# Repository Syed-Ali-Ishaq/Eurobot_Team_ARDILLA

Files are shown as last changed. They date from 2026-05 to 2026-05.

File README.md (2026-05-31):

<p float="left" style="display:flex;justify-content:space-between;padding:0 5em 0 5em">
    
    
</p>
</br>

# Eurobot 2026 - Master Advanced Mechatronics

This is the official baseline repository for the International Challenge of the Master Advanced Mechatronics at Polytech Annecy-Chambéry.

<p style="text-align:center"> &#9888; This project must be run as a Dev Container &#9888; </p>

This year, PROJ703 and PROJ903 have the goal of tackling the challenge set for the Eurobot Contest 2026 (see the [Official Website](https://www.eurobot.org/eurobot-contest/eurobot-2026/)).

> *Winter is coming, and it’s time for the squirrels to stock up on hazelnuts so they can spend the whole winter in their soft, warm nests.</br> 
> But evil humans already took them all, put them in crates and are about to leave with them, and it will let squirrels starving for the next months!</br>
> Luckily it’s coffee time for the humans, and the squirrels have only few seconds to grab the hazelnut crates and hide it from the evil humans.</br>
> But will they have enough to pass the winter?*
>
> *Your strategies will be:*
> - *Let’s keep the hazelnuts warm.*
> - *To find is to keep!*
> - *Not too warm, not too cold.*
> - *Nest, sweet nest.*
> - *Lunch time!*

## Content
- [x] VSCode Dev Container Template (see [Development Container](https://containers.dev/) and [Setup ROS 2 with VSCode and Docker](https://docs.ros.org/en/kilted/How-To-Guides/Setup-ROS-2-with-VSCode-and-Docker-Container.html) for more info) </p>
To be run using one of the available tools (see [Supporting tools and services](https://containers.dev/supporting)) </p>
We suggest running this project on VSCode using the [Dev Containers extension](https://marketplace.visualstudio.com/items?itemName=ms-vscode-remote.remote-containers) (see [Developing inside a Container](https://code.visualstudio.com/docs/devcontainers/containers)) </p>
  - [x] devcontainer.json + Dockerfile based on [ROS 2 Workspace by Bruno-Pier Busque](https://github.com/BrunoB81HK/ros2-workspace-devcontainer-template/tree/main/src/ros2-workspace) (ROS 2 Humble and Ignition Gazebo Fortress on Ubuntu Jammy)
  - [X] ROS 2/Gazebo project template
    - [X] Simple Gazebo world with game mat based on the official Beta mat
    - [X] Simple robot for reference
- [ ] Reference documents

## Guidelines
- [ ] Every team must fork this repository.
- [ ] All team members must be listed as contributors to the corresponding fork.
- [ ] All team members must contribute to the corresponding fork.

</br>

---

<h1 style="text-align:center">
&#128063; Let's code/design/build some squirrels! &#128063;
<h1>

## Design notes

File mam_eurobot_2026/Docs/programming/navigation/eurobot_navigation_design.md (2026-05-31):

# Eurobot Navigation Package — Design Documentation

**Package:** `eurobot_navigation`  
**Team:** Team Yellow (ARDILLA) — Eurobot 2026  
**Files covered:** `MissionController.py`, `scan_frame_fixer.py`, `mapper_params_online_async.yaml`

---

## 1. Package Overview

The navigation package contains three components that work together to give the robot autonomous mobility and mission execution:

| Component | Role |
|---|---|
| `SimpleMissionController` | Top-level FSM — decides what the robot does and when |
| `ScanFrameFixer` | Thin adapter that corrects the LiDAR frame ID for SLAM Toolbox |
| `mapper_params_online_async.yaml` | SLAM Toolbox configuration for online async mapping |

---

## 2. System Architecture

```
[LiDAR driver]
    │  /scan  (wrong frame_id)
    ▼
[ScanFrameFixer]
    │  /scan_fixed  (frame_id = 'lidar_link')
    ▼
[SLAM Toolbox]  ←── mapper_params_online_async.yaml
    │  /map  +  TF: map → odom → base_link
    ▼
[Nav2 stack]  ←── NavigateToPose action server
    ▲
    │  navigate_to_pose action
    │
[SimpleMissionController]
    ├── /cmd_vel  ──────────────────► [robot base]
    ├── /gripper_controller/commands ► [gripper]
    └── /crate/detections ◄─────────── [ArucoCratePerception]
```

---

## 3. `ScanFrameFixer` Node

### Purpose

Some LiDAR drivers publish `/scan` with a generic or incorrect `frame_id` (e.g. `laser` or empty). SLAM Toolbox requires the scan's `frame_id` to match a known TF frame. This node is a **minimal relay** that rewrites the header and republishes.

### How it works

```
/scan  ──► [overwrite header.frame_id = 'lidar_link'] ──► /scan_fixed
```

Every incoming `LaserScan` message is mutated in place — only `header.frame_id` changes, all scan data passes through unchanged.

### Design rationale

Rather than patching the driver or adding a URDF static transform with the wrong name, this tiny node decouples the driver's output format from the SLAM Toolbox's expectation. It costs essentially zero CPU and can be removed once the driver is fixed upstream.

### ROS Interfaces

| Direction | Topic | Type |
|---|---|---|
| Subscribes | `/scan` | `sensor_msgs/LaserScan` |
| Publishes | `/scan_fixed` | `sensor_msgs/LaserScan` |

---

## 4. SLAM Toolbox Configuration (`mapper_params_online_async.yaml`)

SLAM Toolbox runs in **online asynchronous mapping** mode, building a live occupancy grid from LiDAR scans while the robot moves.

### Frame setup

| Parameter | Value | Meaning |
|---|---|---|
| `odom_frame` | `odom` | Wheel odometry frame |
| `map_frame` | `map` | Global SLAM output frame |
| `base_frame` | `base_link` | Robot centre frame |
| `scan_topic` | `/scan_fixed` | Uses the corrected scan from ScanFrameFixer |
| `mode` | `mapping` | Live SLAM (not localisation-only) |

### Key tuning decisions

**Map resolution — 0.05 m/cell (5 cm)**  
Appropriate for Eurobot's 3×2 m table. Fine enough to detect crates (150×50 mm) while keeping the map small enough to update in real time on the Horizon RDK X3 Pi's ARM CPU.

**Map update interval — 5.0 s**  
The published `/map` topic refreshes every 5 seconds. This is intentionally slow to reduce CPU load; the robot's local costmap (managed by Nav2) updates much faster from the live scan.

**Minimum travel thresholds — 0.5 m / 0.5 rad**  
A new scan is only added to the map graph when the robot has moved at least 0.5 m or rotated at least 0.5 rad since the last keyframe. This prevents the map from growing with redundant scans when the robot is nearly stationary (e.g. during grasping).

**Loop closure — enabled**  
`do_loop_closing: true` with a 3 m search radius. On a 3×2 m table the robot will frequently revisit areas, so loop closure is important for keeping the map consistent. The chain size of 10 means at least 10 keyframes must form the loop before it is applied, avoiding spurious corrections.

**Solver — Ceres with Sparse Normal Cholesky**  
The Ceres solver with LEVENBERG_MARQUARDT trust region is a standard robust choice for pose graph optimisation. `SCHUR_JACOBI` preconditioning accelerates convergence on sparse graphs typical of small-environment SLAM.

**LiDAR range — 0.0–20.0 m (for rastering)**  
These are the image rastering bounds used internally by SLAM Toolbox, not a filter on the incoming scan. Actual useful range on the Eurobot table is ≈ 0.1–3.0 m.

**`restamp_tf: false`**  
Timestamps on the published `map → odom` TF transform are taken directly from the scan stamp, not re-stamped to `now()`. This is important for avoiding TF extrapolation errors that were a known issue in simulation.

### Parameter summary table

| Parameter | Value | Effect |
|---|---|---|
| `resolution` | 0.05 m | Grid cell size |
| `map_update_interval` | 5.0 s | How often the `/map` topic is refreshed |
| `minimum_travel_distance` | 0.5 m | Min movement before new keyframe |
| `minimum_travel_heading` | 0.5 rad | Min rotation before new keyframe |
| `scan_buffer_size` | 10 | Rolling buffer of recent scans |
| `do_loop_closing` | true | Enable loop closure correction |
| `loop_search_maximum_distance` | 3.0 m | Max distance to search for loop candidates |
| `transform_timeout` | 0.2 s | Max wait for a TF lookup |
| `tf_buffer_duration` | 30.0 s | How long TF history is kept |
| `enable_interactive_mode` | true | Allows RViz-based map editing |

---

## 5. `SimpleMissionController` Node

### Purpose

This is the robot's brain. It reads crate detections from the perception node, drives the robot through a simple linear state machine to collect a crate of the team colour, and returns it to the home/deposit zone using Nav2.

### State Machine

```
        ┌─────────────────────────────────────────────────────────┐
        │                                                         │
   ┌────▼────┐   1 s    ┌───────────┐   1.5 s  ┌────────┐        │
   │  INIT   ├─────────►│ EXIT_ZONE ├──────────►│ SEARCH │        │
   └─────────┘          └───────────┘           └───┬────┘        │
  open gripper         drive forward              rotate/nudge    │
                                                    │             │
                              detection seen        │             │
                              ◄─────────────────────┘             │
                              │                                   │
                         ┌────▼────────┐                          │
                         │ GO_TO_CRATE │  lost crate → SEARCH     │
                         └─────┬───────┘                          │
                    proportional servo                            │
                    (linear + angular)                            │
                               │ dist ≤ 0.15 m                   │
                          ┌────▼────┐                             │
                          │  GRAB   │  2 s close gripper          │
                          └────┬────┘                             │
                               │                                  │
                          ┌────▼────┐                             │
                          │ BACKUP  │  1 s reverse                │
                          └────┬────┘                             │
                               │                                  │
                          ┌────▼────┐                             │
                          │ GO_HOME │  Nav2 NavigateToPose        │
                          └────┬────┘  retry on failure           │
                               │ succeeded                        │
                          ┌────▼────┐                             │
                          │ RELEASE │  1.5 s open gripper         │
                          └────┬────┘                             │
                               │                                  │
                          ┌────▼────┐                             │
                          │ SUCCESS │─────────────────────────────┘
                          └─────────┘  (TODO: loop back to SEARCH)
```

### State descriptions

#### `INIT` (1 second)
Opens the gripper to ensure a known starting position. Transitions to `EXIT_ZONE` after 1 s.

#### `EXIT_ZONE` (1.5 seconds)
Drives forward at 0.2 m/s to clear the starting zone boundary. Pure open-loop timed move — no sensing required. Transitions to `SEARCH`.

#### `SEARCH`
Rotates in place at 0.4 rad/s, scanning for crates. This gives a full 360° sweep in approximately 16 s. After each full rotation, nudges forward by 0.15 m/s for one tick to change viewpoint if no crate is found.

Transitions to `GO_TO_CRATE` as soon as `has_recent_detection()` returns true (a detection of the correct team colour within the last 2 s).

#### `GO_TO_CRATE`
Visual servoing loop running at 10 Hz. The robot drives directly toward the closest valid crate using two proportional controllers:

**Angular controller:**
```
angular_speed = −angle_rad × 1.5
clamped to [−0.4, +0.4] rad/s
```
The negative sign corrects the convention: a positive bearing angle (crate to the left) requires negative (clockwise) rotation to centre it.

**Linear controller:**
```
distance_error = distance − grasp_distance   (grasp_distance = 0.15 m)
linear_speed   = distance_error × 0.8
clamped to [0.02, 0.30] m/s
```
The floor of 0.02 m/s prevents the robot from stopping just short of the crate due to proportional controller droop. The 0.15 m grasp distance is chosen so the crate is within gripper reach without the camera losing sight of the marker (camera FOV loss occurs below ~0.20 m).

If the crate is lost mid-approach (`has_recent_detection()` returns false), the robot stops and returns to `SEARCH`.

> ⚠️ **Angle unit note:** The detection message's `angle` field is published in **degrees** by the perception node (see `aruco_crate_perception.py` line 679), but the mission controller treats it as **radians**. This means there is currently a unit mismatch — the angular gain of 1.5 effectively operates on a much larger number than intended. The comment in the code (`# FIX 1`) acknowledges this: if the detector publishes degrees, a `math.radians(d.angle)` conversion should be added here.

#### `GRAB` (2 seconds)
Closes the gripper by publishing `[−0.04, −0.04]` to `/gripper_controller/commands`. After 2 s sets `crate_grabbed = True` and transitions to `BACKUP`.

#### `BACKUP` (1 second)
Drives in reverse at −0.15 m/s to pull the crate away from its original position and give Nav2 room to plan a path. After 1 s transitions to `GO_HOME`.

#### `GO_HOME`
Sends a `NavigateToPose` goal to Nav2 targeting `(HOME_X, HOME_Y, HOME_YAW)` — by default `(0.3, 0.3, 0.0)` in the map frame. This is where the deposit zone is.

The goal is sent **once** on first entry (detected by `_nav_goal_handle is None and _nav_result is None`). The state then waits for the async result callback. On failure, the goal is reset and retried indefinitely (a retry counter is noted as a TODO).

Nav2 feedback (distance remaining) is logged at every feedback tick.

#### `RELEASE` (1.5 seconds)
Opens the gripper by publishing `[+0.04, +0.04]`, depositing the crate. Sets `crate_grabbed = False` after 1.5 s, transitions to `SUCCESS`.

#### `SUCCESS`
Stops the robot and logs mission completion. Currently terminal — a TODO exists to loop back to `SEARCH` if match time remains.

---

### Visual Servoing Controller Summary

| Parameter | Value | Notes |
|---|---|---|
| Angular gain | 1.5 | Applied to angle in radians |
| Angular clamp | ±0.4 rad/s | Prevents over-spinning |
| Linear gain | 0.8 | Applied to distance error |
| Linear clamp | 0.02–0.30 m/s | Floor avoids droop; ceiling avoids collisions |
| Grasp distance | 0.15 m | Stop threshold (within gripper reach) |
| Detection timeout | 2.0 s | Maximum age of a "recent" detection |

---

### Detection Filtering in the Controller

`on_detection()` filters the incoming `CrateDetectionArray` to keep only entries where:
- `color == self.team_color` (default: `'yellow'`)
- `confidence > 0.3`

Among the valid detections it selects the **closest** one by `distance`. This means the robot always pursues the nearest accessible crate of its colour, which is the greedy-optimal strategy for Eurobot scoring.

---

## 6. ROS Interfaces — `SimpleMissionController`

### Subscriptions

| Topic | Type | Purpose |
|---|---|---|
| `/crate/detections` | `eurobot_interfaces/CrateDetectionArray` | Crate position and colour from perception |

### Publications

| Topic | Type | Purpose |
|---|---|---|
| `/cmd_vel` | `geometry_msgs/Twist` | Drive commands to robot base |
| `/gripper_controller/commands` | `std_msgs/Float64MultiArray` | Gripper open/close commands |

### Action Clients

| Action | Type | Purpose |
|---|---|---|
| `navigate_to_pose` | `nav2_msgs/NavigateToPose` | Autonomous navigation to home pose |

---

## 7. Key Configuration Constants

These are hardcoded at the top of `MissionController.py` and should be updated before each match:

| Constant | Default | Description |
|---|---|---|
| `HOME_X` | 0.3 m | X coordinate of deposit zone in map frame |
| `HOME_Y` | 0.3 m | Y coordinate of deposit zone in map frame |
| `HOME_YAW` | 0.0 rad | Robot heading at deposit zone |
| `self.team_color` | `'yellow'` | Which crate colour to collect |
| `self.grasp_distance` | 0.15 m | Stop distance for grasping |

---

## 8. Known Issues & TODOs

| Issue | Location | Notes |
|---|---|---|
| Angle unit mismatch | `GO_TO_CRATE` | Perception publishes degrees; controller treats as radians. Add `math.radians(d.angle)` conversion. |
| No retry limit on GO_HOME | `GO_HOME` | Nav2 failure retries indefinitely. Add a counter and fall back gracefully. |
| No multi-crate loop | `SUCCESS` | After one successful delivery, the robot stops. Loop back to `SEARCH` to collect more crates. |
| Open-loop EXIT_ZONE | `EXIT_ZONE` | 1.5 s forward drive is not distance-controlled; result varies with battery voltage. |
| HOME pose hardcoded | top of file | Should be a ROS parameter or loaded from a config file. |

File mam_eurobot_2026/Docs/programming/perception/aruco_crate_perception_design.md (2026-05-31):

# ArUco Crate Perception Node — Design Documentation

**Package:** `eurobot_perception`  
**Node name:** `aruco_crate_perception`  
**File:** `aruco_crate_perception.py`  
**Team:** Team Yellow (ARDILLA) — Eurobot 2026

---

## 1. Purpose

This node is the robot's "eyes" for finding hazelnut crates on the competition field. It reads frames from a USB camera, detects ArUco markers attached to the crates, estimates each crate's position relative to the robot, applies temporal filtering to suppress noise, and publishes reliable crate detections to the rest of the system.

---

## 2. High-Level Data Flow

```
/camera  (sensor_msgs/Image)
    │
    ▼
[image_callback]
    │
    ├─► detect_markers()
    │       │  ArUco detection (OpenCV)
    │       │  Pose estimation (solvePnP)
    │       │  camera_to_base_link() transform
    │       │  Distance + angle computation
    │       │  Outlier rejection
    │       │  Confidence scoring
    │       └─► updates TrackedCrate objects
    │
    ├─► get_filtered_detections()
    │       └─► weighted moving average over TrackedCrate history
    │
    ├─► Publish  /crate/detections  (CrateDetectionArray)
    │
    └─► Publish  /crate/debug       (Image, if visualize=True)

/camera_info  (sensor_msgs/CameraInfo)  [optional]
    └─► camera_info_callback()
            └─► replaces default pinhole model with calibrated K + D
```

---

## 3. Key Classes

### 3.1 `TrackedCrate` (dataclass)

Maintains a short history of detections for a single marker ID so that temporal filtering can be applied.

| Field | Type | Description |
|---|---|---|
| `marker_id` | int | ArUco ID of this crate |
| `color` | str | `'blue'`, `'yellow'`, or `'empty'` |
| `positions` | `deque(maxlen=N)` | Recent `(x, y)` positions in base_link (m) |
| `distances` | `deque(maxlen=N)` | Recent Euclidean distances (m) |
| `angles` | `deque(maxlen=N)` | Recent bearing angles (rad) |
| `confidences` | `deque(maxlen=N)` | Recent confidence scores [0–1] |
| `last_seen` | float | ROS time (s) of latest detection |
| `detection_count` | int | Total detections since first seen |

**Filtering method:** all `get_filtered_*()` methods apply a **linearly increasing weight** (`np.linspace(0.5, 1.0, N)`) so the most recent reading has twice the influence of the oldest. This is a simple but effective approximation of a low-pass filter without the state-estimation complexity of a Kalman filter.

**Stability gate:** `is_stable(min_detections)` — a tracked crate is only forwarded to the mission controller once it has been seen at least `min_stable_detections` times (default 2). This prevents single-frame ghost detections from triggering robot motion.

---

### 3.2 `ArucoCratePerception` (ROS 2 Node)

The main node class. Responsibilities are split into clearly labelled sections:

| Section | Methods | What it does |
|---|---|---|
| Initialization | `_declare_parameters`, `_load_parameters`, `_validate_parameters` | ROS parameter system setup and sanity checks |
| ArUco setup | `_setup_aruco` | Builds the dictionary, detector parameters, and the marker→color mapping |
| Camera model | `_setup_camera_model`, `camera_info_callback` | Constructs a default pinhole matrix; overrides it with calibrated values if `/camera_info` is received |
| Coordinate transform | `camera_to_base_link` | Rotates the ArUco translation vector from camera frame into robot base_link frame |
| Detection | `detect_markers` | Per-frame detection pipeline: ArUco → pose → transform → filter → confidence |
| Temporal filtering | `get_filtered_detections`, `_cleanup_old_tracks` | Aggregates per-marker histories; prunes stale tracks |
| Confidence | `compute_confidence`, `_corner_quality` | Scores each detection 0–1 |
| Visualization | `draw_detection` | Draws bounding boxes, axes, labels, and arrows on the debug image |
| Main callback | `image_callback` | Orchestrates all of the above on every incoming frame |

---

## 4. Detection Pipeline (per frame)

```
image_callback()
│
├── 1. Convert ROS Image → OpenCV BGR frame (cv_bridge)
│
├── 2. detect_markers(frame, timestamp)
│       a. Convert to grayscale
│       b. aruco.detectMarkers() → corners, ids, rejected
│       c. aruco.estimatePoseSingleMarkers() → rvecs, tvecs  (one per marker)
│       d. For each detected marker ID:
│           i.   Skip if ID not in ARUCO_IDS map
│           ii.  camera_to_base_link(tvec) → (x_base, y_base)
│           iii. Compute distance = √(x² + y²)
│           iv.  Compute bearing angle = atan2(y, x)
│           v.   Skip if distance outside [min_distance, max_distance]
│           vi.  is_outlier() — skip if position jumped > max_position_jump
│           vii. compute_confidence() — skip if below min_confidence
│           viii.Update TrackedCrate history
│           ix.  Append to raw_detections list
│
├── 3. get_filtered_detections()   (if enable_filtering=True)
│       — iterate TrackedCrate dict
│       — skip unstable tracks (detection_count < min_stable_detections)
│       — return weighted-average position/distance/angle/confidence
│
├── 4. Publish CrateDetectionArray on /crate/detections
│       — angle is published in DEGREES (converted from radians here)
│
└── 5. Publish debug image on /crate/debug  (if visualize=True)
```

---

## 5. Coordinate Transform

The camera is mounted on the front of the robot with a downward pitch (`camera_pitch ≈ 0.7 rad ≈ 40°`).

**Frame conventions:**

| Frame | X | Y | Z |
|---|---|---|---|
| Camera (OpenCV) | right | down | forward (optical axis) |
| Robot base_link | forward | left | up |

**Transform steps in `camera_to_base_link(tvec)`:**

1. **Pitch rotation** around the camera's X-axis (removes the tilt):
   ```
   y_int = y_cam·cos(pitch) + z_cam·sin(pitch)
   z_int = −y_cam·sin(pitch) + z_cam·cos(pitch)
   x_int = x_cam
   ```

2. **Axis remap** to base_link:
   ```
   x_base = z_int + camera_x_offset   (camera forward → robot forward)
   y_base = −x_int                    (camera right  → robot left = negative Y)
   ```

The `camera_x_offset` (default 0.10 m) accounts for the camera being mounted in front of the robot's geometric centre.

---

## 6. Confidence Scoring

`compute_confidence()` returns a value in [0, 1] as a weighted sum of four sub-scores:

| Sub-score | Weight | What it measures |
|---|---|---|
| Corner quality | 0.30 | How square/regular the detected corners are (ratio of opposite sides and diagonals) |
| Distance score | 0.30 | Inverse-normalized distance; closer = higher |
| Angle score | 0.20 | How frontal the view is; 0° bearing = 1.0, ±90° = 0.0 |
| Size score | 0.20 | Marker perimeter as a fraction of image perimeter; larger = more reliable |

A detection is only forwarded if `confidence ≥ min_confidence` (default 0.30).

---

## 7. Outlier Rejection

Before updating the tracker, `is_outlier()` computes the Euclidean jump from the last known position. If `jump > max_position_jump` (default 0.50 m), the detection is discarded and a throttled warning is logged. This guards against momentary false positives caused by reflections or partial occlusions.

---

## 8. ROS Interfaces

### Subscriptions

| Topic | Type | Purpose |
|---|---|---|
| `/camera` (configurable) | `sensor_msgs/Image` | Input camera frames |
| `/camera_info` | `sensor_msgs/CameraInfo` | Optional calibrated intrinsics |

### Publications

| Topic | Type | Description |
|---|---|---|
| `/crate/detections` | `eurobot_interfaces/CrateDetectionArray` | Stable, filtered crate list |
| `/crate/debug` | `sensor_msgs/Image` | Annotated debug frame (if `visualize=True`) |

### `CrateDetection` message fields

| Field | Unit | Notes |
|---|---|---|
| `color` | string | `'blue'`, `'yellow'`, `'empty'` |
| `x` | m | Forward distance in base_link |
| `y` | m | Lateral offset in base_link (positive = left) |
| `distance` | m | Euclidean range |
| `angle` | **degrees** | Bearing from robot heading |
| `confidence` | [0–1] | Detection quality score |

> ⚠️ Note: `angle` is stored internally in **radians** but **published in degrees**. Consumers of `/crate/detections` must expect degrees.

---

## 9. Parameters Reference

| Parameter | Default | Description |
|---|---|---|
| `camera_topic` | `/camera` | Image subscription topic |
| `image_width` / `image_height` | 640 / 480 | Expected resolution |
| `focal_length` | 277.0 px | Default pinhole focal length |
| `marker_size` | 0.04 m | Physical ArUco marker side length (40 mm) |
| `aruco_dict` | `DICT_4X4_50` | ArUco dictionary |
| `min_distance` | 0.10 m | Minimum valid detection range |
| `max_distance` | 6.0 m | Maximum valid detection range |
| `min_confidence` | 0.30 | Minimum confidence to keep a detection |
| `min_marker_perimeter` | 30 px | Smallest accepted marker in pixels |
| `camera_pitch` | 0.7 rad | Camera tilt angle (downward positive) |
| `camera_x_offset` | 0.10 m | Camera forward offset from base_link origin |
| `camera_z_offset` | 0.20 m | Camera height (informational; not used in current transform) |
| `base_frame` | `base_link` | Output frame ID for published detections |
| `enable_filtering` | True | Enable temporal filtering |
| `filter_history_size` | 5 | Deque length per tracked crate |
| `min_stable_detections` | 2 | Detections required before publishing |
| `tracking_timeout` | 1.0 s | Stale track removal threshold |
| `enable_outlier_rejection` | True | Enable position-jump filter |
| `max_position_jump` | 0.50 m | Maximum inter-frame position change |
| `visualize` | True | Publish annotated debug image |
| `show_fps` | True | Log FPS periodically |

---

## 10. Marker ID Mapping

| ArUco ID | Crate colour |
|---|---|
| 36 | Blue |
| 47 | Yellow |
| 41 | Empty |

All other IDs detected in the frame are silently ignored.

---

## 11. Design Decisions & Trade-offs

**Weighted moving average instead of Kalman filter.** A full Kalman filter would give better noise rejection but requires tuning process/measurement noise matrices and adds complexity. The linearly-weighted deque is sufficient for the slow-moving crates in Eurobot and easier to debug on hardware.

**No TF publishing.** Positions are published as fields in the custom message rather than as TF transforms. This keeps the perception node self-contained and avoids TF tree complexity during the competition.

**Calibrated vs. default camera model.** The node starts with a simple pinhole model (square pixels, principal point at image centre). If `/camera_info` is received, it silently upgrades to the calibrated matrix and distortion coefficients. This makes the node usable even without a calibration file.

**Angle published in degrees.** The conversion happens at publish time (`math.degrees(det['angle'])`). Internal tracking always uses radians. This is a deliberate choice for human-readability in `ros2 topic echo` but requires all downstream consumers (e.g. the mission controller) to treat the angle field as degrees.

---

## 12. Performance Monitoring

- `frame_count` and `detection_count` are accumulated every callback.
- Every second (when `show_fps=True`) the node logs FPS and total detections at INFO level.
- A 0.5 s timer calls `_cleanup_old_tracks()` to prune stale entries from `tracked_crates`, preventing unbounded memory growth.

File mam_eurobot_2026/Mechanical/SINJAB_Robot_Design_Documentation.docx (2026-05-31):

# Robot Design Documentation – SINJAB

## 1. Introduction

The project 'SINJAB' is a circular robot designed with the primary goal of collecting nuts and delivering them to the nest. The design was created using SolidWorks and aims to provide efficient and stable movement while maintaining a compact structure.

## 2. Robot Specifications

Robot Name: SINJAB

Purpose: To get the nuts to the nest, move the cursor

CAD Software: SolidWorks

Shape and Dimensions: Square Robot with dimensions of 240x360 so it will fit the 1200mm in parameter as required for the rules

Main Components: Body, Wheels, Grip, Stem, emergency bottom, Bacon

Material: 3D printed plastic (PLA), metal/plastic sheets (if available)

Drive System: Two wheels with Two casters for support

Mechanical Team Members: Hussein Youssef and Bashir Awad and Gauthier Djerabe

## 3. Design Overview

The SINJAB robot was modeled in SolidWorks using a modular approach. The design consists of a main circular body housing the motors and electronics, a stem supporting the head and grip mechanism, and two driven wheels with a rear and front caster for balance.

## 4. Component Breakdown

• Body: The main structure that holds all components together.
• Wheels: Two driven wheels provide movement and are supported by a front caster.
• Grip: A 100 mm parallel jaw mechanism designed to pick up nuts.
• Head: Contains sensors or visual components for detection and control.

## 5. Materials and Manufacturing

The entire robot structure is designed to be plastic/metal material. This choice provides a lightweight, cost-effective, and easily replaceable structure suitable for prototyping and testing.

## 6. Drive System

SINJAB uses a differential drive system consisting of two powered wheels and Two caster for stability. This setup allows the robot to move forward, backward, and rotate around its axis for precise navigation.

## 7. Conclusion

The SINJAB robot represents a compact and efficient design ideal for nut collection and delivery tasks. Its simple mechanical structure and 3D-printed build make it highly suitable for testing, improvement, and educational applications.

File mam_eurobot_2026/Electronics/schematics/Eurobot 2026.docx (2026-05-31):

Eurobot 2026- Electronic System Documentation for Team Ardilla

Schematic References:

- Sensor_IO
- Power_and_Distribution
- Power_and_Motion

# 1 Overview of Electronic Architecture

The electronic system of the robot is organized into three main subsystems: sensor interfacing, power management and motion control. These subsystems are distributed across three schematics to ensure modularity, clarity and ease of debugging.

The architecture follows a functional separation approach:

- The Sensor_IO board manages acquisition and conditioning of sensor signals, including I²C multiplexing and ADC conversion.
- The Power_and_Distribution board regulates and distributes electrical power to all subsystems, it receives the battery through connector J1 (XT60), protects it with fuse F1 (10 A) and distributes filtered V12V and V5V rails to all subsystems
- The Power_and_Motion board handles actuator control, via two TB6612FNG dual H-bridge drivers (U1, U2) and monitors current with INA219AXD (U3)

This modular design improves reliability, simplifies integration and allows independent development and testing of each subsystem.

# 2 Power Supply and Distribution Subsystem

## 2.1 Power Input and Protection

The system is powered from the main robot battery connected to J1 – XT60, which is dimensioned for high current and secure mechanical locking.
Downstream of the connector, fuse F1 (10 A) on the V12V line provides over-current protection against short circuits and excessive load, in accordance with competition robustness requirements.

A rocker switch SW1 – Inter à bascule 10 A / 12 V is placed in series with the fused line to act as the main power switch, allowing safe power-up, shutdown and emergency cut-off.
Test point TP1 – V12V gives direct access to the protected 12 V rail for debugging and measurement.

Bulk capacitor C1 (220 µF / 25 V) is connected across V12V and GND to smooth input voltage fluctuations and reduce the effect of sudden current transients from the motion subsystem.
Ground reference is made accessible through TP3 – GND, simplifying probing across the system.

## 2.2 Voltage Regulation

The Power_and_Distribution board defines and labels the main power nets: VBATT, V12V and V5V, using KiCad PWR_FLAG symbols to explicitly mark intended power sources. Voltage regulation circuits are implemented to provide stable voltage rails required by the system. These regulated supplies are used by:

- Control electronics
- Sensor interfaces
- Logic components

Decoupling capacitors (for example, U4 – LD1117V33) are placed near power outputs to reduce high-frequency noise and stabilize voltage during dynamic load changes.

## 2.3 Power Distribution

The regulated voltage rails are distributed across the robot clearly labeled nets and multiple screw terminal connectors: J2, J3, J4, J5, J6, J7 – Bornier 2-pin 5.08 mm (or optional 2-pin 2.54 mm headers ) These connectors fan out the V12V and V5V rails to the Power_and_Motion board and Sensor_IO board.

Test point TP2 – V5V provides a convenient measurement point for the 5 V distribution rail, enabling quick verification during assembly and debugging

This ensures clean and organized routing of power and reliable supply to all subsystems, as well as keeping wiring organized and simplifying isolation of subsystems

# 3 Sensor Interface Subsystem

## 3.1 Sensor Connectivity

The Sensor_IO board standardizes sensor connections by exposing dedicated headers for each sensor, typically providing VCC3V3 or VCC5V, GND and one or more signal lines (analog or digital). Examples include the ultrasonic sensor connectors J1 / J2 (TRIG/ECHO and power) and generic sensor headers J3, J10, J11 for free signal lines (SENSSIGLIBRE1, SENSSIGLIBRE2) and switches (SWITCHIN)

Analog sensors are connected to the ADC U3 – ADS1115IDGS via connectors J6, J7, J8, J9, each providing VCC3V3, GND and one ADC input channel (AIN0–AIN3 / AIN4–AIN7 as labeled)

This uniform connector scheme simplifies integration, replacement and swapping of sensors without modifying the main harness.

## 3.2 Signal Conditioning

Passive components such as resistors and capacitors are used to condition incoming signals before they reach the main controller or ADC.
For digital lines, pull-up networks like R2 (4.7 kΩ) on the I²C bus and R3 (10 kΩ), R4 (20 kΩ), R5 (10 kΩ), R7 (10 kΩ), R8 (10 kΩ) on TRIG/ECHO and free sensor lines define stable logic levels and ensure compatibility with 3.3 V inputs (ECHOIN3V3, SENSSIGLIBRE1, SENSSIGLIBRE2).

Decoupling capacitors C1 (10 µF) and C2–C5 (100 nF) around the 3.3 V regulator U4 – LD1117V33 filter supply noise for sensor electronics and digital ICs.
This ensures that sensor outputs are stable, reliable and compatible with the microcontroller and ADC interfaces.

I²C Multiplexing and ADC Conversion

The board integrates an I²C multiplexer U2 – TCA9548A to support multiple groups of I²C sensors without address conflicts.
The main I²C bus (SDAMAIN, SCLMAIN) from the controller, pulled up to VCC3V3 via R2 and R6 (10 kΩ), enters U2 and is internally routed to up to eight downstream channels (SC0/SD0 … SC7/SD7, labeled I2CCH0–I2CCH7).

Address pins A0, A1, A2 are tied to GND, fixing the TCA9548A I²C address and simplifying software configuration.
Each channel can host one or more I²C sensors, enabling multiple identical devices to coexist on separate sub-buses while the main controller sees only one I²C address.

The ADC U3 – ADS1115IDGS digitizes analog sensor signals on its AIN0–AIN3 inputs and communicates over I²C with the main controller through the same 3.3 V bus.
This combination of I²C multiplexing and high-resolution ADC conversion provides flexible and scalable sensor interfacing for the robot.

## 3.3 Signal Routing

All conditioned sensor signals and control lines are routed to the main controller through the 24-pin connector J12 – Conn02x12.
This connector carries:

- Power: VCC5V, VCC3V3, GND
- Communication: SDAMAIN, SCLMAIN, I2CSDA, I2CSCL
- Sensor/control signals: TRIGOUT, ECHOIN3V3, SWITCHIN, SENSSIGLIBRE1, SENSSIGLIBRE2
- Motion-related signals: M1PWM, M1DIR1, M1DIR2, M2PWM, M2DIR1, M2DIR2, M1ENCA, M1ENCB, M2ENCA, M2ENCB

This organization improves schematic readability and simplifies debugging and signal tracing, because each net is clearly labeled and grouped by function.

## 3.4 Protection considerations

Basic protection is provided at the connector and signal level: pull-ups and series resistors limit current into sensitive IC pins in case of wiring mistakes, and the global fuse F1 on the Power_and_Distribution board protects against severe faults.
Additional improvements, such as adding TVS diodes on external sensor connectors or series resistors on particularly exposed lines, can be considered for future revisions.

# 4 Power and Motion Subsystem

## 4.1 Motor Driver Architecture

The motion subsystem is built around two dual H-bridge driver ICs U1 and U2 – TB6612FNG, each capable of driving one DC motor with bidirectional control and PWM speed regulation.
The logic supply VCC (5 V) and motor supply VM1–VM3 are provided via the Power_and_Distribution board, while outputs M1OUT1/M1OUT2 (for U1) and M2OUT1/M2OUT2 (for U2) connect directly to the motor terminals.

Separating logic and motor supply pins, and using dedicated power grounds PGND1, PGND2, reduces noise coupling from high currents into control electronics.
The STBY pin allows enabling or disabling each driver, providing a low-power standby mode and an additional safety lever in software.

## 4.2 Control Interface

Control signals from the main controller are received via J3 – Conn01x10, which provides 5V, GND, M1PWM, M1DIR1, M1DIR2, M2PWM, M2DIR1, M2DIR2, and I2CSDA/I2CSCL for the current sensor.
Inside each TB6612FNG, the direction inputs (AIN1, AIN2, BIN1, BIN2) are driven by the DIR signals, while PWMA/PWMB receive the PWM signals (M1PWM, M2PWM) to set motor speed.

This mapping allows the controller to define motor behavior through simple logic and PWM:

- Logic combinations on DIR pins define forward, reverse, brake and coast modes.
- PWM duty cycle on PWM pins sets the effective motor voltage and therefore speed.

## 4.3 Output Stage

The output stage consists of the TB6612FNG H-bridge transistors and their connections to the motors via the M1OUT1/M1OUT2 and M2OUT1/M2OUT2 pins. These outputs are dimensioned to handle the expected motor current and are tied to dedicated power ground pins to manage return currents efficiently.

The high-current path (battery → F1 → VMx → TB6612FNG → motors) is kept physically and electrically separate from sensitive analog and digital signals wherever possible, limiting noise coupling.poweranddistributionboard.pdf+1
Local bulk capacitors on the motor supply help limit voltage dips and transients during switching events.

## 4.4 Current Sensing and Monitoring (INA219)

To monitor power consumption of the motion subsystem, the board integrates a current/voltage monitor U3 – INA219AXD.
The device measures the voltage across a low-value shunt resistor R1 (0.1 Ω) inserted in series with the motor supply line (IN+ / IN-) and reports current and bus voltage over I²C.

The INA219 is connected to the controller via I2CSDA, I2CSCL coming from J3, with pull-ups R2, R3 (4.7 kΩ) to 5 V ensuring proper I²C levels.
Address pins A0, A1 are wired to configure the device’s I²C address, allowing the controller to identify it on the bus and log or react to current measurements.

This monitoring can be used for diagnostics (stall detection, energy profiling) and for implementing software-based safety limits.

Encoder Inputs and Feedback

Quadrature encoder signals for the two motors are brought in through connectors J4 and J5 – Conn01x04, which expose M1ENCA/M1ENCB and M2ENCA/M2ENCB respectively along with 5 V supply.
Pull-up resistors R4, R5, R6, R7 (4.7 kΩ) on these lines ensure clean logic levels for the controller’s interrupt inputs.

These encoder signals are forwarded to the main controller via the Sensor_IO connector J12, enabling closed-loop speed and position control.
This structure keeps high-current motor wiring on the Power_and_Motion board while routing only low-power encoder lines to the logic domain.

## 4.5 Local Power Regulation and Filtering

Several capacitors (C1, C2, C6 – 100 nF and C5, C7, C8 – 10 µF) are placed close to the TB6612FNG ICs and the INA219 shunt to locally stabilize both logic and motor supply rails.
These components reduce switching noise produced by PWM operation, protect against voltage spikes and prevent interference with the I²C current sensor and other digital logic.

# 5 System Integration

The three schematics work together as follows:

- The Power_and_Distribution board receives the battery via J1 (XT60), protects it with F1 (10 A), filters it with C1/C2 and distributes V12V and V5V through J2–J7 to the rest of the robot.
- The Sensor_IO board uses U4 – LD1117V33 to generate VCC3V3, multiplexes I²C with U2 – TCA9548A, converts analog signals with U3 – ADS1115IDGS, and exposes all sensor and control lines through J12 to the main controller.
- The Power_and_Motion board uses U1/U2 – TB6612FNG to drive the motors based on PWM/DIR signals from J3, and U3 – INA219AXD to monitor current consumption over I²C.

This architecture cleanly separates power distribution, sensor interfacing and motion control, making the system easier to debug, upgrade and validate for the Eurobot 2026 competition.

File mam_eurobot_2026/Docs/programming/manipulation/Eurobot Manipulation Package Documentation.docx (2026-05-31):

Eurobot Manipulation Package Documentation

1. Project Overview

1.1 High-Level Goal

The eurobot_manipulator package provides gripper control functionality for the Eurobot autonomous robot. It enables the robot to:

- Grasp colored crates detected by the perception system
- Hold objects securely during navigation
- Release crates at designated pantry locations
- Detect contact using finger-mounted sensors to prevent over-gripping
- Coordinate with the task manager for autonomous pick-and-place operations
- Respond to both autonomous commands and manual control inputs

The gripper uses a parallel-jaw design with two finger joints, controlled via position commands and equipped with contact sensors for tactile feedback.

1.2 System Architecture

The manipulation package consists of a single intelligent node:

gripper_controller - State machine-based gripper controller with contact sensing

The controller implements a robust state machine that manages gripper behavior:

- Initializing - Startup sequence, opens gripper to home position
- Idle - Ready to receive commands
- Closing - Actively closing until contact or limit reached
- Gripping - Holding an object with sustained grip force
- Opening - Actively opening to release object

1.3 Hardware and Simulation Environment

- Platform: ROS 2 Humble
- Simulation: Gazebo with ros_gz_bridge
- Actuators: 2 position-controlled finger joints (left_finger_joint, right_finger_joint)
- Sensors: Contact sensors on both gripper fingers
- Control Rate: 20 Hz command loop
- Controller: ros2_control with JointGroupPositionController

1.4 Design Philosophy

The gripper controller is designed with robustness and safety in mind:

- Contact-based feedback: Stops closing when object is detected to prevent damage
- State machine logic: Clear, deterministic behavior transitions
- Dual command interface: Supports both autonomous (task_manager) and manual control
- Fail-safe behavior: Detects empty grasps and returns to idle state
- Real-time monitoring: Publishes gripper state for system awareness

2. Package Summary

Package Name

eurobot_manipulator

Goal

Provide reliable, contact-sensing gripper control for autonomous crate manipulation in the Eurobot competition.

Dependencies

ROS 2 Packages:

- rclpy - ROS 2 Python client library
- std_msgs - String messages for commands and state
- sensor_msgs - JointState messages for position feedback
- geometry_msgs - (available for future use)
- control_msgs - Control system interfaces
- trajectory_msgs - Trajectory control (available for future use)
- ros_gz_interfaces - Gazebo contact sensor messages

External Systems:

- ros2_control - Controller manager and interfaces
- controller_manager - Runtime controller management
- position_controllers - JointGroupPositionController

Main Nodes

Node Name | Purpose | Type
gripper_controller | State machine-based gripper control with contact sensing | Full Implementation

Configuration Files

gripper_controller.yaml - Contains configuration for:

- Controller manager parameters (update rate: 100 Hz)
- Joint state broadcaster configuration
- Gripper controller parameters (joints, interfaces, rates)

Interaction with Other Packages

Integration with eurobot_navigation:

- Subscribes to /manipulation/command (CrateManipulation) - planned integration
- Subscribes to /gripper/command (String) - direct manual control
- Publishes /gripper/state (String) - gripper status for monitoring

Hardware Interface:

- Publishes to /gripper_controller/commands (Float64MultiArray) - position commands
- Subscribes to /joint_states (JointState) - current finger positions
- Subscribes to /gripper/left/contact and /gripper/right/contact (Contacts) - tactile feedback

3. Node-Level Documentation

3.1 Node: gripper_controller

Node Name

gripper_controller_node

Goal / Functionality

Implements a state machine-based gripper controller that manages parallel-jaw gripper operation with contact sensing. The node:

1. Controls finger positions via incremental position commands
2. Monitors contact sensors on both fingers to detect object grasping
3. Implements state machine for robust grip/release behavior
4. Prevents over-gripping by stopping closure when contact is detected
5. Publishes state for system monitoring and coordination
6. Supports dual command interface for autonomous and manual control

Subscribed Topics

Topic | Type | Purpose
/gripper/command | std_msgs/String | Manual control commands ("open", "close")
/manipulation/command | eurobot_interfaces/CrateManipulation | Autonomous commands from task_manager (planned)
/joint_states | sensor_msgs/JointState | Current finger joint positions and velocities
/gripper/left/contact | ros_gz_interfaces/Contacts | Left finger contact sensor data
/gripper/right/contact | ros_gz_interfaces/Contacts | Right finger contact sensor data

Published Topics

Topic | Type | Purpose
/gripper_controller/commands | std_msgs/Float64MultiArray | Position commands [left_pos, right_pos]
/gripper/state | std_msgs/String | Current gripper state for monitoring

Parameters

Currently no ROS parameters - all values are hardcoded constants:

Constant | Value | Description
min_pos | -0.03 | Minimum finger position (fully closed)
max_pos | 0.03 | Maximum finger position (fully open)
step | 0.005 | Position increment per control cycle
Control rate | 20 Hz | Main control loop frequency (0.05s timer)
Init rate | 1 Hz | Initialization timer frequency

State Machine

The gripper operates in five distinct states:

1. INITIALIZING
  - Initial state on startup
  - Waits 1 second, then sends OPEN command [0.03, 0.03]
  - Transitions to IDLE
2. IDLE
  - Ready to receive commands
  - No motion, maintains current position
  - Accepts "open" or "close" commands
3. CLOSING
  - Incrementally decreases finger positions (step = -0.005 per cycle)
  - Monitors contact sensors continuously
  - Stops individual finger when contact detected
  - Transitions to GRIPPING when both fingers detect contact
  - Transitions to IDLE if fully closed without contact (empty grasp warning)
4. GRIPPING
  - Maintains current position to hold object
  - No further motion
  - Accepts "open" command to release
5. OPENING
  - Incrementally increases finger positions (step = +0.005 per cycle)
  - Continues until max_pos (0.03) reached
  - Transitions to IDLE when fully open
  - Can be commanded from IDLE, GRIPPING, or CLOSING states

Internal State Variables

# Sensor feedback

left_contact: bool # True if left finger detects contact

right_contact: bool # True if right finger detects contact

# Joint positions (from /joint_states)

left_pos: float # Current left finger position

right_pos: float # Current right finger position

joint_initialized: bool # True after first joint_states received

# State machine

state: str # "initializing", "idle", "closing", "gripping", "opening"

# Initialization

init_sent: bool # True after initialization command sent

Algorithm Flow

Initialization Sequence:

def initialize_gripper():

IF not init_sent:

# Send open command

publish [0.03, 0.03] to /gripper_controller/commands

LOG: "Gripper initialized to OPEN"

state = "idle"

init_sent = True

cancel init_timer

Command Callback (command_callback):

def command_callback(msg):

command = msg.data.lower()

IF command == "close":

close_gripper()

ELSE IF command == "open":

open_gripper()

ELSE:

WARN: "Unknown gripper command: {command}"

Contact Sensor Callbacks:

def left_contact_cb(msg):

left_contact = (len(msg.contacts) > 0)

IF left_contact AND state == "closing":

LOG: "Left finger contact!" (throttled to 1Hz)

def right_contact_cb(msg):

right_contact = (len(msg.contacts) > 0)

IF right_contact AND state == "closing":

LOG: "Right finger contact!" (throttled to 1Hz)

Joint State Callback:

def joint_state_cb(msg):

TRY:

idx_left = msg.name.index('left_finger_joint')

idx_right = msg.name.index('right_finger_joint')

left_pos = msg.position[idx_left]

right_pos = msg.position[idx_right]

IF not joint_initialized:

joint_initialized = True

LOG: "Joint states: left={left_pos}, right={right_pos}"

EXCEPT (ValueError, IndexError):

pass # Joint names not found

Main Control Loop (20 Hz):

def control_loop():

# 1. Publish current state

publish state to /gripper/state

# 2. State-specific behavior

IF state == "initializing":

return # Wait for initialization

ELSE IF state == "closing":

# Check if grasp achieved

IF left_contact AND right_contact:

state = "gripping"

LOG: "Crate grasped!"

return

# Incrementally close each finger until contact

IF not left_contact AND left_pos > min_pos:

left_pos -= step # Decrease by 0.005

IF not right_contact AND right_pos > min_pos:

right_pos -= step

# Check if fully closed without contact (empty grasp)

IF left_pos <= min_pos AND right_pos <= min_pos:

IF not (left_contact AND right_contact):

WARN: "Gripper fully closed but no object!"

state = "idle"

ELSE IF state == "opening":

# Incrementally open

IF left_pos < max_pos:

left_pos += step

IF right_pos < max_pos:

right_pos += step

# Check if fully open

IF left_pos >= max_pos AND right_pos >= max_pos:

LOG: "Gripper fully opened"

state = "idle"

ELSE IF state == "gripping":

pass # Hold current position

ELSE IF state == "idle":

pass # No motion

# 3. Clamp positions to valid range

left_pos = clamp(left_pos, min_pos, max_pos)

right_pos = clamp(right_pos, min_pos, max_pos)

# 4. Publish position commands

publish [left_pos, right_pos] to /gripper_controller/commands

Close Gripper:

def close_gripper():

IF state in ["idle", "opening"]:

LOG: "Closing gripper..."

state = "closing"

left_contact = False

right_contact = False

ELSE:

WARN: "Cannot close in state: {state}"

Open Gripper:

def open_gripper():

IF state in ["idle", "gripping", "closing"]:

LOG: "Opening gripper..."

state = "opening"

left_contact = False

right_contact = False

ELSE:

WARN: "Cannot open in state: {state}"

Contact Sensing Logic

The gripper uses contact sensors to implement adaptive grasping:

1. During CLOSING:
  - Each finger closes independently until contact is detected
  - Contact detection: len(msg.contacts) > 0
  - When a finger touches the crate, it stops moving
  - The other finger continues until it also makes contact
  - This allows grasping objects that may not be perfectly centered
2. Grasp Confirmation:
  - State transitions to GRIPPING only when both fingers detect contact
  - This ensures a secure two-point grasp
3. Empty Grasp Detection:
  - If both fingers reach min_pos (-0.03) without contact
  - Log warning: "Gripper fully closed but no object!"
  - Transition to IDLE (ready for retry)
4. Contact Reset:
  - Contact flags reset to False when entering CLOSING or OPENING states
  - Prevents false positives from previous grasps

4. Topic Communication Summary

4.1 Node Communication Table

Node | Publishes | Subscribes | Message Type | Description
gripper_controller | /gripper_controller/commands | /gripper/command | Float64MultiArray | Position commands [left, right]
| /gripper/state | /manipulation/command | String | Current gripper state
| | /joint_states | CrateManipulation (planned) | Commands from task_manager
| | /gripper/left/contact | JointState | Joint position feedback
| | /gripper/right/contact | Contacts | Contact sensor data

4.2 Message Format Details

Float64MultiArray (Position Commands)

# Published to /gripper_controller/commands

data: [left_finger_pos, right_finger_pos] # Both in range [-0.03, 0.03]

String (Command Input)

# Subscribed from /gripper/command

data: "open" or "close" # Case-insensitive

String (State Output)

# Published to /gripper/state

data: "initializing" | "idle" | "closing" | "gripping" | "opening"

Contacts (Contact Sensors)

# Subscribed from /gripper/{left|right}/contact

contacts: [

# List of Contact messages, empty if no contact

{

collision1_name: "gripper::left_finger::collision",

collision2_name: "crate::collision",

position: Point3D,

normal: Vector3D,

depth: float

}

]

# Contact detected if: len(msg.contacts) > 0

JointState (Position Feedback)

# Subscribed from /joint_states

name: ["left_finger_joint", "right_finger_joint", ...]

position: [0.025, 0.020, ...] # Corresponding positions

velocity: [0.0, 0.0, ...]

effort: [0.0, 0.0, ...]

4.3 Integration Topics (Planned)

CrateManipulation (from task_manager)

# Will subscribe to /manipulation/command

int32 crate_id # ID of crate being manipulated

int32 command # 0=PICK, 1=PLACE

Planned Integration Logic:

def manipulation_command_cb(msg):

IF msg.command == 0: # PICK

close_gripper()

LOG: "Picking crate {msg.crate_id}"

ELSE IF msg.command == 1: # PLACE

open_gripper()

LOG: "Placing crate {msg.crate_id}"

5. Configuration Details

5.1 gripper_controller.yaml

File Location: eurobot_manipulator/config/gripper_controller.yaml

Controller Manager Configuration

controller_manager:

ros__parameters:

update_rate: 100 # Hz - High rate for smooth control

use_sim_time: true # Using Gazebo simulation

# Registered controllers

joint_state_broadcaster:

type: joint_state_broadcaster/JointStateBroadcaster

gripper_controller:

type: position_controllers/JointGroupPositionController

Parameters Explained:

- update_rate: 100 - Controller manager runs at 100Hz for responsive control
- use_sim_time: true - Synchronize with Gazebo simulation time
- Controller types registered for spawning at runtime

Joint State Broadcaster

joint_state_broadcaster:

ros__parameters:

use_sim_time: true

Purpose: Publishes /joint_states topic containing current positions, velocities, and efforts of all joints.

Gripper Controller

gripper_controller:

ros__parameters:

use_sim_time: true

joints:

- left_finger_joint

- right_finger_joint

command_interfaces:

- position

state_interfaces:

- position

- velocity

allow_partial_joints_goal: false

state_publish_rate: 50.0

action_monitor_rate: 20.0

Parameters Explained:

Parameter | Value | Purpose
joints | [left_finger_joint, right_finger_joint] | Controlled joint names (must match URDF)
`command_

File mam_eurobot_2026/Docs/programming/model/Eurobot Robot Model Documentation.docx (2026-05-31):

Eurobot Robot Model Documentation

Physical Design & Gazebo Simulation Configuration

1. Robot Overview

1.1 High-Level Description

The simple_robot is a differential-drive mobile manipulator designed for the Eurobot competition. It features:

- Mobile base: Differential drive with two powered wheels and one passive caster
- Manipulator: Parallel-jaw gripper for picking and placing crates
- Sensors: 2D LiDAR for mapping/navigation and RGB camera for object detection
- Simulation: Full Gazebo integration with physics, sensors, and control

1.2 Robot Dimensions

Component | Dimension | Value
Base Length | X-axis | 280 mm (0.28 m)
Base Width | Y-axis | 250 mm (0.25 m)
Base Height | Z-axis | 70 mm (0.07 m)
Total Mass | - | ~3.86 kg
Wheelbase | Center-to-wheel | 140 mm (0.14 m) per side
Ground Clearance | - | 15 mm (wheel bottom)

1.3 Design Philosophy

The robot is designed for:

- Stability: Low center of gravity with wide wheelbase
- Maneuverability: Differential drive for precise turning
- Manipulation: Front-mounted gripper optimized for 150mm x 100mm x 30mm crates
- Perception: 360° LiDAR coverage and forward-facing camera
- Modularity: Clean separation between base, sensors, and manipulator

2. Mechanical Design

2.1 Overall Layout

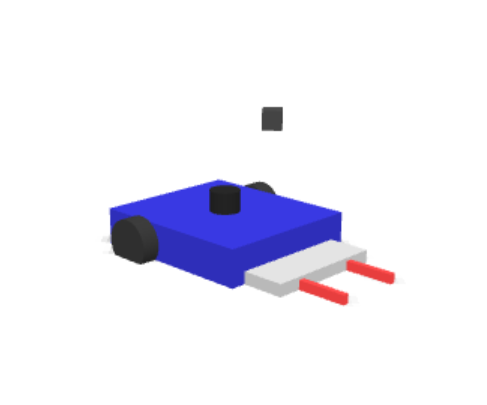
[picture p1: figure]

2.2 Component Positioning

Base Link (Center of robot coordinate system):

- Position: (0, 0, 0.025) - Base center at wheel axle height (25mm)
- This places wheel centers at ground level (z=0)

Gripper Base:

- Position: (0.17, 0, -0.02) relative to base_link
- 17cm forward from robot center (front-mounted)
- 2cm below base center for optimal crate pickup height

Wheels:

- Left: (-0.06, 0.14, 0) - 6cm behind center, 14cm left
- Right: (-0.06, -0.14, 0) - 6cm behind center, 14cm right
- Positioned 80mm from rear edge for weight distribution

Caster:

- Position: (0.11, 0, -0.02) - 11cm forward, 2cm below base
- Provides front support and smooth rotation

Sensors:

- LiDAR: (0, 0, 0.05) - Centered on top of base, 5cm high
- Camera: (0.10, 0, 0.20) - 10cm forward, 20cm high, tilted down 0.7 rad (40°)

3. Link Descriptions

3.1 Base Link

Name: base_link (canonical link)

Purpose: Main robot body, serves as primary reference frame

Geometry:

- Shape: Box
- Dimensions: 280mm × 250mm × 70mm (L × W × H)
- Position: (0, 0, 0.025) relative to model origin

Inertial Properties:

Mass: 3.0 kg

Inertia Tensor:

Ixx = 0.0186 kg⋅m²

Iyy = 0.0228 kg⋅m²

Izz = 0.0391 kg⋅m²

Material: Blue color (RGB: 0.2, 0.2, 0.8)

Collision: Full box collision for obstacle detection

3.2 Base Footprint

Name: base_footprint

Purpose: Ground-level reference frame for navigation

Position: (0, 0, -0.025) relative to base_link (at ground level z=0)

Type: Virtual link (no geometry or mass)

Connection: Fixed joint to base_link

3.3 Wheel Links

Left Wheel

Name: left_wheel

Geometry:

- Shape: Cylinder
- Radius: 40mm (80mm diameter)
- Width: 30mm

Position: (-0.06, 0.14, 0) relative to base_link

- Orientation: Rotated -90° (π/2 rad) around X-axis to align with Y-axis motion

Inertial Properties:

Mass: 0.3 kg

Inertia: Ixx = Iyy = 0.00024 kg⋅m², Izz = 0.00048 kg⋅m²

Surface Properties:

- Friction: μ = μ₂ = 1.0 (high traction)
- Contact stiffness: kp = 1×10⁶ N/m
- Contact damping: kd = 100 N⋅s/m
- No slip allowed

Right Wheel

Name: right_wheel

Specifications: Identical to left wheel

Position: (-0.06, -0.14, 0) (mirrored on Y-axis)

3.4 Caster Wheel

Name: caster

Purpose: Passive front support, allows smooth rotation

Geometry:

- Shape: Sphere
- Radius: 20mm (40mm diameter)

Position: (0.11, 0, -0.02) relative to base_link

- 110mm forward from center (30mm from front edge)
- 20mm below base center (matches wheel ground clearance)

Inertial Properties:

Mass: 0.05 kg

Inertia: All components = 0.00008 kg⋅m²

Surface Properties:

- Friction: μ = μ₂ = 0.01 (very low for free rolling)
- Slip: slip₁ = slip₂ = 1.0 (allows omnidirectional motion)

3.5 Gripper Links

Gripper Base

Name: gripper_base

Purpose: Mounting platform for finger actuators

Geometry:

- Shape: Box
- Dimensions: 80mm × 200mm × 30mm

Position: (0.17, 0, -0.02) relative to base_link

- Mounted at front of robot
- Height optimized for 30mm tall crate pickup

Inertial Properties:

Mass: 0.3 kg

Inertia: All components ≈ 0.0002 kg⋅m²

Material: Gray/silver (RGB: 0.7-0.9)

Left Finger

Name: left_finger

Geometry:

- Shape: Box
- Dimensions: 160mm × 10mm × 20mm (L × W × H)

Position: (0.04, 0.055, 0.0) relative to gripper_base

- 4cm forward, 5.5cm left of gripper center
- Positioned to grip 150mm (long side) of crate

Inertial Properties:

Mass: 0.08 kg

Inertia: Ixx = Izz = 0.00008, Iyy = 0.00002 kg⋅m²

Material: Red (RGB: 0.9, 0.3, 0.3)

Surface Properties:

- High friction: μ = μ₂ = 8.0 (prevents slippage during gripping)
- Contact stiffness: kp = 1×10⁶ N/m
- Max contact velocity: 0.01 m/s
- Min penetration depth: 0.001 m

Sensor: Contact sensor (left_finger_contact)

- Type: Contact detection
- Update rate: 200 Hz
- Topic: /gripper/left/contact

Right Finger

Name: right_finger

Specifications: Identical to left finger

Position: (0.04, -0.055, 0.0) (mirrored on Y-axis)

Sensor: Contact sensor (right_finger_contact)

- Topic: /gripper/right/contact

3.6 Sensor Links

LiDAR Link

Name: lidar_link

Purpose: 2D laser scanner mounting point

Geometry:

- Shape: Cylinder
- Radius: 25mm
- Height: 40mm

Position: (0, 0, 0.05) relative to base_link

- Centered on top of base
- 50mm above base center for clear 360° view

Inertial Properties:

Mass: 0.1 kg

Inertia: All components = 0.00002 kg⋅m²

Sensor Configuration: See Section 5.1

Camera Link

Name: camera_link

Purpose: RGB camera mounting point

Geometry:

- Shape: Box (small cube)
- Dimensions: 30mm × 30mm × 30mm

Position: (0.10, 0, 0.20) relative to base_link

- 10cm forward
- 20cm high
- Pitch angle: 0.7 rad (≈40° downward tilt)

Inertial Properties:

Mass: 0.05 kg

Inertia: All components = 0.00001 kg⋅m²

Sensor Configuration: See Section 5.2

4. Joint Specifications

4.1 Wheel Joints

Left Wheel Joint

Name: left_wheel_joint

Type: Revolute (continuous rotation)

Parent: base_link
Child: left_wheel

Axis: (0, 0, 1) - Rotation around Z-axis (after link orientation)

Limits:

- Lower: -1×10¹⁶ rad (effectively unlimited)
- Upper: +1×10¹⁶ rad
- Effort: 10 N⋅m (URDF), unlimited (SDF)
- Velocity: 10 rad/s (URDF), unlimited (SDF)

Control: Velocity-controlled via diff_drive plugin

Right Wheel Joint

Name: right_wheel_joint

Specifications: Identical to left wheel joint (mirrored)

4.2 Gripper Joints

Left Finger Joint

Name: left_finger_joint

Type: Prismatic (linear motion)

Parent: gripper_base
Child: left_finger

Axis: (0, 1, 0) - Motion along Y-axis (lateral)

Limits:

Lower: -0.03 m (closed position, 3cm inward)

Upper: +0.03 m (open position, 3cm outward)

Effort: 40 N (maximum force)

Velocity: 0.05 m/s (5 cm/s max speed)

Dynamics:

- Damping: 3.0 N⋅s/m (smooth motion)
- Friction: 0.5 N (realistic resistance)

Control Interface: Position-controlled via ros2_control

- Command: Position setpoint (-0.03 to +0.03 m)
- State: Position, velocity, effort feedback

Right Finger Joint

Name: right_finger_joint

Type: Prismatic

Axis: (0, -1, 0) - Opposite direction (symmetric closing)

Limits: Same as left finger (-0.03 to +0.03 m)

Note: Negative Y-axis ensures both fingers move toward center when closing

4.3 Fixed Joints

Joint Name | Parent | Child | Purpose
base_to_footprint | base_link | base_footprint | Navigation reference
caster_joint | base_link | caster | Front support
gripper_base_joint | base_link | gripper_base | Gripper mounting
lidar_joint | base_link | lidar_link | Sensor mounting
camera_joint | base_link | camera_link | Sensor mounting

5. Sensor Configuration

5.1 LiDAR Sensor

Sensor Name: lidar_sensor

Type: gpu_lidar (GPU-accelerated ray tracing)

Topic: /scan

Frame: lidar_link

Update Rate: 10 Hz

Configuration:

Horizontal Scan:

Samples: 360 (1° resolution)

Range: -π to +π rad (full 360°)

Vertical Scan:

Samples: 1 (2D planar scan)

Range:

Minimum: 0.08 m (8 cm)

Maximum: 10.0 m

Resolution: 0.01 m (1 cm)

Noise:

Type: Gaussian

Mean: 0.0 m

Std Dev: 0.01 m (1 cm)

Always On: Yes
Visualization: Enabled

Published Message: sensor_msgs/LaserScan

ranges: float32[360] # Distance measurements

angle_min: -3.14159

angle_max: 3.14159

angle_increment: 0.01745 (1°)

range_min: 0.08

range_max: 10.0

Use Cases:

- SLAM mapping (slam_toolbox)
- Localization (AMCL)
- Obstacle detection (Nav2 costmaps)

5.2 Camera Sensor

Sensor Name: camera_sensor

Type: camera (RGB image)

Topic: /camera

Frame: camera_link

Update Rate: 30 Hz

Configuration:

Field of View:

Horizontal FOV: 1.047 rad (60°)

Image:

Width: 320 pixels

Height: 240 pixels

Format: R8G8B8 (RGB, 8-bit per channel)

Clipping Planes:

Near: 0.1 m

Far: 100 m

Noise:

Type: Gaussian

Mean: 0.0

Std Dev: 0.007 (per pixel intensity)

Always On: Yes
Visualization: Enabled

Published Messages:

- /camera/image_raw (sensor_msgs/Image)
- /camera/camera_info (sensor_msgs/CameraInfo)

Mounting:

- Tilted 0.7 rad (40°) downward
- Optimized for detecting objects at 0.5-2m range on ground

Use Cases:

- Crate detection (eurobot_perception)
- Pantry detection (eurobot_perception)
- Visual servoing (future)

5.3 Contact Sensors

Left Finger Contact Sensor

Sensor Name: left_finger_contact

Type: contact

Topic: /gripper/left/contact

Monitored Collision: left_finger_collision

Update Rate: 200 Hz

Always On: Yes

Published Message: ros_gz_interfaces/Contacts

contacts: [

{

collision1_name: "simple_robot::left_finger::left_finger_collision"

collision2_name: "crate::collision" (example)

position: Point3D

normal: Vector3D

depth: float

}

]

Contact Detection Logic:

has_contact = len(msg.contacts) > 0

Right Finger Contact Sensor

Sensor Name: right_finger_contact

Specifications: Identical to left sensor

Topic: /gripper/right/contact

Purpose:

- Detect when fingers touch crate
- Enable adaptive grasping (stop closing on contact)
- Confirm successful grip (both fingers in contact)

6. Actuator Systems

6.1 Differential Drive System

Control Method: Velocity-based differential drive

Controlled Joints:

- left_wheel_joint
- right_wheel_joint

Physical Parameters:

Wheel Separation: 0.28 m (280 mm between wheels)

Wheel Radius: 0.04 m (40 mm, 80 mm diameter)

Velocity Limits:

Max Linear Velocity: 1.0 m/s

Max Angular Velocity: 2.0 rad/s (≈115°/s)

Max Linear Acceleration: 2.0 m/s²

Max Angular Acceleration: 3.0 rad/s²

Odometry Publishing:

- Topic: /odom
- Frame: odom → base_link
- Frequency: 50 Hz

Command Interface:

- Topic: /cmd_vel
- Type: geometry_msgs/Twist

linear.x: Forward/backward velocity (m/s)

angular.z: Rotation velocity (rad/s)

Transform Publishing:

- Topic: /tf
- Publishes: odom → base_link transform
- Dead reckoning based on wheel encoders

6.2 Gripper Actuation

Control Method: Position control via ros2_control

Controlled Joints:

- left_finger_joint (prismatic)
- right_finger_joint (prismatic)

Hardware Interface: ign_ros2_control/IgnitionSystem

Controller Type: position_controllers/JointGroupPositionController

Controller Name: gripper_controller

Command Interface:

- Topic: /gripper_controller/commands
- Type: std_msgs/Float64MultiArray
- Format: [left_position, right_position]
- Units: meters
- Range: -0.03 to +0.03 m per finger

State Interfaces:

- Position (current finger positions)
- Velocity (finger motion speed)
- Effort (force applied)

Published States:

- Topic: /joint_states
- Type: sensor_msgs/JointState
- Frequency: 50 Hz
- Includes: left_finger_joint, right_finger_joint positions/velocities

Example Commands:

# Fully open

msg.data = [0.03, 0.03]

# Fully closed

msg.data = [-0.03, -0.03]

# Asymmetric (e.g., during contact-based closing)

msg.data = [0.01, -0.02] # Left partial, right closed

7. Gazebo Plugins

7.1 Differential Drive Plugin

Plugin: libignition-gazebo-diff-drive-system.so

Name: ignition::gazebo::systems::DiffDrive

Configuration:

<left_joint>left_wheel_joint</left_joint>

<right_joint>right_wheel_joint</right_joint>

<wheel_separation>0.28</wheel_separation>

<wheel_radius>0.04</wheel_radius>

<odom_publish_frequency>50</odom_publish_frequency>

<topic>cmd_vel</topic>

<odom_topic>odom</odom_topic>

<tf_topic>/tf</tf_topic>

<frame_id>odom</frame_id>

<child_frame_id>base_link</child_frame_id>

Functionality:

- Converts /cmd_vel (Twist) to wheel velocities
- Simulates wheel physics and friction
- Publishes odometry (position integration from wheel encoders)
- Publishes TF transforms

7.2 Joint State Publisher Plugin

Plugin: libignition-gazebo-joint-state-publisher-system.so

Name: ignition::gazebo::systems::JointStatePublisher

Published Joints:

- left_wheel_joint
- right_wheel_joint
- left_finger_joint
- right_finger_joint

Topic: /joint_states

Update Rate: 50 Hz

Published Data:

name: [joint names]

position: [joint angles/positions in rad/m]

velocity: [joint velocities in rad/s or m/s]

effort: [joint torques/forces in N⋅m or N]

7.3 Sensors System Plugin

Plugin: libignition-gazebo-sensors-system.so

Name: ignition::gazebo::systems::Sensors

Render Engine: ogre2 (3D graphics rendering)

Functionality:

- Enables all sensor simulations (LiDAR, camera, contacts)
- Manages sensor update loops
- Renders camera images and raycasts LiDAR beams

7.4 Pose Publisher Plugin

Plugin: libignition-gazebo-pose-publisher-system.so

Name: ignition::gazebo::systems::PosePublisher

Configuration:

<publish_link_pose>true</publish_link_pose>

<publish_nested_model_pose>true</publish_nested_model_pose>

<use_pose_vector_msg>true</use_pose_vector_msg>

<static_publisher>true</static_publisher>

<static_update_frequency>10</static_update_frequency>

Functionality:

- Publishes poses of all links
- Useful for debugging and visualization
- Topic: /model/simple_robot/pose (Gazebo-specific)

7.5 Contact System Plugin

Plugin: libignition-gazebo-contact-system.so

Name: ignition::gazebo::systems::Contact

Functionality:

- Enables contact sensor simulation
- Detects collisions on gripper fingers
- Publishes contact messages to specified topics

7.6 ROS 2 Control Bridge Plugin

Plugin: libign_ros2_control-system.so

Name: ign_ros2_control::IgnitionROS2ControlPlugin

Parameters File: /root/eurobot_ws/src/mam_eurobot_2026/models/simple_robot/gripper_controller.yaml

Functionality:

- Bridges Gazebo simulation with ros2_control
- Exposes gripper joints to ros2_control framework
- Enables controller_manager to spawn controllers

8. ROS 2 Control Integration

8.1 Hardware Interface

System Name: GripperSystem

Type: system

Plugin: ign_ros2_control/IgnitionSystem

Controlled Joints:

1. left_finger_joint
2. right_finger_joint

8.2 Joint Interfaces

Per Joint Configuration

Command Interface:

- Type: position
- Min: -0.03 m
- Max: +0.03 m

State Interfaces:

- position - Current joint position
- velocity - Current joint velocity
- effort - Current joint force/torque

8.3 Controller Manager

Update Rate: 100 Hz

Loaded Controllers:

1. joint_state_broadcaster (JointStateBroadcaster)
  - Publishes /joint_states
  - Update rate: 50 Hz
2. gripper_controller (JointGroupPositionController)
  - Subscribes: /gripper_controller/commands
  - Controls: Both finger joints simultaneously
  - Update rate: 50 Hz
  - Action monitoring: 20 Hz

9. Coordinate Frames

9.1 Frame Tree

map

└─ odom (published by diff_drive or AMCL)

└─ base_footprint

└─ base_link (canonical, robot center)

├─ left_wheel

├─ right_wheel

├─ caster

├─ lidar_link

├─ camera_link

└─ gripper_base

├─ left_finger

└─ right_finger

9.2 Key Frame Descriptions

Frame | Purpose | Parent | Transform
map | Global reference (SLAM/localization) | - | Fixed world frame
odom | Odometry reference (drifts over time) | map | From AMCL or odometry
base_footprint | Ground-level navigation reference | odom | (0, 0, 0) at ground
base_link | Robot center, primary body frame | base_footprint | (0, 0, 0.025)
lidar_link | LiDAR sensor frame | base_link | (0, 0, 0.05)
camera_link | Camera optical frame | base_link | (0.1, 0, 0.2), pitch=0.7
gripper_base | Gripper mounting frame | base_link | (0.17, 0, -0.02)
left_finger | Left gripper finger | gripper_base | (0.04, 0.055+joint, 0)
right_finger | Right gripper finger | gripper_base | (0.04, -0.055+joint, 0)

9.3 Transform Publishers

Static Transforms (fixed joints):

- Published by robot_state_publisher from URDF/SDF
- Includes: base_link → sensors, base_link → gripper_base, etc.

Dynamic Transforms:

- odom → base_link: Published by diff_drive plugin or AMCL
- Gripper joint positions: Updated by ros2_control via joint_states

10. Physical Properties

10.1 Mass Distribution

Component | Mass (kg) | Percentage
Base Link | 3.00 | 77.7%
Left Wheel | 0.30 | 7.8%
Right Wheel | 0.30 | 7.8%
Gripper Base | 0.30 | 7.8%
Left Finger | 0.08 | 2.1%
Right Finger | 0.08 | 2.1%
LiDAR | 0.10 | 2.6%
Camera | 0.05 | 1.3%
Caster | 0.05 | 1.3%
Total | 3.86 kg | 100%

10.2 Inertia Tensors

Base Link (largest contributor):

Ixx = 0.0186 kg⋅m² (roll inertia)

Iyy = 0.0228 kg⋅m² (pitch inertia)

Izz = 0.0391 kg⋅m² (yaw inertia)

- Higher Izz reflects wider base (harder to rotate in yaw)

Wheels (rotating masses):

Ixx = Iyy = 0.00024 kg⋅m² (bending resistance)

Izz = 0.00048 kg⋅m² (spin inertia, 2× radial)

10.3 Friction Coefficients

Surface | μ (static/kinetic) | Purpose
Wheels | 1.0 | High traction, no slip
Caster | 0.01 | Free rolling, minimal drag
Gripper Fingers | 8.0 | Secure grip, prevent object slip

10.4 Contact Parameters

Wheels and Caster:

- Stiffness (kp): 1×10⁶ N/m (rigid contact)
- Damping (kd): 100 N⋅s/m (prevent bouncing)

Gripper Fingers:

- Stiffness: 1×10⁶ N/m
- Max velocity: 0.01 m/s (slow penetration)
- Min depth: 0.001 m (1mm sensitivity)

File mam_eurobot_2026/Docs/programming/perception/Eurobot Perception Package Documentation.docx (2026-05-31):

Eurobot Perception Package Documentation

1. Package Overview

High-Level Goal

The eurobot_perception package provides vision-based object detection capabilities for an autonomous robot competing in the Eurobot competition. The system detects colored crates (blue and yellow) and green pantries in real-time using camera input, converting pixel-space detections into robot-relative coordinates for navigation and manipulation planning.

System Overview

The perception system uses computer vision techniques to identify and localize game objects in the robot's environment. It processes camera images through HSV color filtering, contour detection, and geometric transformation to produce actionable detection data that downstream systems can use for task planning and navigation.

Key capabilities:

- Real-time detection of blue and yellow crates
- Detection of green pantries for crate placement
- Distance and angle estimation using pinhole camera model
- Robot-relative coordinate conversion (meters)
- Configurable detection parameters
- Debug visualization support

Hardware and Testing Environment

- Simulation Platform: Gazebo
- ROS Version: ROS 2 Humble
- Sensors: RGB Camera (simulated)
- Visualization: RViz,

2. Package Summary

Package Name

eurobot_perception

Goal

Provide robust, real-time perception capabilities for detecting game objects (crates and pantries) and converting visual information into spatial data usable by navigation and task management systems.

Dependencies

- rclpy - ROS 2 Python client library
- sensor_msgs - Standard ROS image messages
- std_msgs - Standard message headers
- cv_bridge - Converts between ROS and OpenCV images
- eurobot_interfaces - Custom message definitions for detections
- OpenCV (cv2) - Computer vision processing
- NumPy - Numerical operations

Main Nodes

Node Name | Purpose
crate_perception | Detects blue and yellow crates, estimates distance and position
pantry_detection | Detects green pantries for crate placement targets

Configuration Files

No dedicated YAML configuration files are currently used. All parameters are declared programmatically within the nodes and can be overridden via command-line or launch file parameters.

Launch Files

No launch files are currently implemented. Nodes are executed individually using ros2 run commands.

Interaction with Other Packages

The perception package publishes detection data that would be consumed by:

- Task Manager - Receives crate and pantry locations to plan pickup/placement sequences
- Navigation - Uses object positions to plan paths and avoid obstacles
- Manipulator - Uses precise object coordinates for gripper positioning

3. Node-Level Explanation

3.1 Crate Perception Node

Node Name

crate_perception

Goal / Functionality

Detects blue and yellow crates in the camera field of view, estimates their distance and bearing relative to the robot, and publishes structured detection messages containing robot-relative coordinates in meters.

Subscribed Topics

Topic | Message Type | Purpose
/camera/image_raw | sensor_msgs/Image | Raw camera feed for processing (configurable)

Published Topics

Topic | Message Type | Purpose
/crate/detections | eurobot_interfaces/CrateDetectionArray | Array of detected crates with position, color, and confidence
/crate/image_debug | sensor_msgs/Image | Annotated debug visualization (only if visualize=True)

Parameters

Parameter | Type | Default | Description
camera_topic | string | /camera/image_raw | Input camera topic name
visualize | bool | True | Enable debug image publishing
min_area | int | 2000 | Minimum contour area (pixels) to consider valid
known_crate_width | float | 0.12 | Physical width of crate in meters
focal_length_px | float | 600.0 | Camera focal length in pixels (calibration)
camera_center_offset | float | 0.0 | Camera mounting offset from robot center (meters)

Main Logic Flow

1. Image Acquisition: Receives RGB image from camera topic and converts to OpenCV format using cv_bridge
2. Color Space Conversion: Converts BGR to HSV color space for robust color detection
3. Color Filtering: For each target color (blue, yellow):
  - Creates binary mask using HSV range thresholds
  - Applies morphological closing to reduce noise
4. Contour Detection: Finds external contours in each color mask
5. Filtering: Rejects contours smaller than min_area threshold
6. Geometric Analysis: For each valid contour:
  - Computes bounding rectangle and centroid
  - Estimates distance using pinhole camera model: distance = (object_width × focal_length) / pixel_width
  - Calculates bearing angle from image center using arctan2
  - Converts to robot-relative Cartesian coordinates (x forward, y lateral)
  - Computes confidence score based on relative contour area
7. Message Publishing: Packages all detections into CrateDetectionArray and publishes
8. Visualization: If enabled, annotates frame with bounding boxes and coordinate labels

Color Detection Ranges (HSV)

Blue: H: [95-135], S: [80-255], V: [40-255]

Yellow: H: [20-35], S: [100-255], V: [100-255]

Coordinate Transformation

The node converts from pixel coordinates to robot-relative meters:

distance = (crate_width × focal_length) / pixel_width

angle_rad = atan2(pixel_offset_x, focal_length)

robot_x = distance × cos(angle_rad) + camera_offset

robot_y = distance × sin(angle_rad)

Where robot_x is forward and robot_y is lateral offset.

3.2 Pantry Detection Node

Node Name

pantry_detection_node

Goal / Functionality

Detects green-colored pantries (target zones for crate placement) in the camera view, assigns unique IDs to each pantry, and publishes their robot-relative positions. Implements duplicate detection filtering to avoid re-detecting the same pantry.

Subscribed Topics

Topic | Message Type | Purpose
/camera/color/image_raw | sensor_msgs/Image | RGB camera feed (configurable)

Published Topics

Topic | Message Type | Purpose
/pantry/detections | eurobot_interfaces/PantryDetectionArray | Array of detected pantries with ID and position

Parameters

Parameter | Type | Default | Description
camera_topic | string | /camera/color/image_raw | Input camera topic
debug_view | bool | True | Display OpenCV debug window
green_lower_hsv | int[3] | [40, 40, 40] | Lower HSV threshold for green
green_upper_hsv | int[3] | [80, 255, 255] | Upper HSV threshold for green
min_area | int | 5000 | Minimum contour area in pixels
known_pantry_width | float | 0.15 | Physical width of pantry in meters
focal_length_px | float | 600.0 | Camera focal length in pixels
camera_center_offset | float | 0.0 | Camera offset from robot center

Main Logic Flow

1. Image Reception: Receives and converts RGB image to OpenCV format
2. HSV Conversion: Converts to HSV color space
3. Green Masking: Creates binary mask for green color range
4. Morphological Operations:
  - Opening to remove small noise
  - Closing to fill gaps
5. Contour Extraction: Finds external contours in mask
6. Size Filtering: Rejects contours below min_area
7. Position Calculation: For each valid contour:
  - Computes centroid and bounding box
  - Estimates distance using pinhole model
  - Calculates bearing angle
  - Transforms to robot-relative coordinates (x, y in meters)
8. Duplicate Filtering: Checks if pantry location is within 0.5m of previously detected pantries
9. ID Assignment: Assigns incremental unique ID to new pantries
10. Publishing: Publishes PantryDetectionArray with all new detections
11. Visualization: If debug enabled, displays annotated frame with OpenCV window

Duplicate Detection Logic

# Avoid re-detecting the same pantry

if not any(hypot(rel_x - px, rel_y - py) < 0.5

for px, py in detected_pantries):

# This is a new pantry

assign_new_id()

4. Topic Communication Summary

System-Wide Topic Flow

Node | Publishes | Subscribes | Message Type | Description
crate_perception | /crate/detections | /camera/image_raw | CrateDetectionArray | Crate positions with color, distance, angle
crate_perception | /crate/image_debug | - | sensor_msgs/Image | Debug visualization (optional)
pantry_detection_node | /pantry/detections | /camera/color/image_raw | PantryDetectionArray | Pantry positions with unique IDs

Message Definitions

CrateDetection.msg

string color # "blue" or "yellow"

float32 x # x coordinate in robot frame (meters, forward)

float32 y # y coordinate in robot frame (meters, lateral)

float32 distance # estimated distance to crate in meters

float32 angle # angle relative to robot heading in degrees

float32 confidence # detection confidence (0.0 - 1.0)

CrateDetectionArray.msg

std_msgs/Header header

CrateDetection[] detections

PantryDetection.msg

int32 id # unique pantry ID

float32 x # x coordinate in robot frame (meters, forward)

float32 y # y coordinate in robot frame (meters, lateral)

float32 distance # estimated distance to pantry in meters

float32 angle # angle relative to robot heading in degrees

float32 confidence # optional: detection confidence (0.0 - 1.0)

PantryDetectionArray.msg

std_msgs/Header header

PantryDetection[] detections

Detection Event Flow

1. Continuous Monitoring: Both perception nodes continuously process incoming camera frames
2. Independent Detection: Crate and pantry detection operate independently on separate topics
3. Real-Time Publishing: Detections are published immediately when objects are found
4. Downstream Consumption: Detection messages are designed to be consumed by higher-level planning systems
5. Coordinate System: All positions are in robot-relative frame (x forward, y lateral, in meters)

Expected Runtime Behavior

Crate Detection:

- Node starts and subscribes to camera topic
- When blue or yellow objects appear in view:
  - Publishes CrateDetectionArray messages
  - Debug image shows green bounding boxes with labels like "blue 1.23m (1.20,0.15)"
- No output if no crates are visible

Pantry Detection:

- Node starts and subscribes to camera topic
- When green objects appear:
  - Assigns unique incremental IDs (Pantry 1, Pantry 2, ...)
  - Publishes PantryDetectionArray messages
  - OpenCV window shows annotated detections
  - Filters duplicate detections within 0.5m radius

5. Simplified System Explanation

The eurobot_perception package gives the robot "eyes" to see game objects. It uses a camera to capture images, then applies color filtering to find blue and yellow crates or green pantries. Once an object is spotted, the system calculates how far away it is and at what angle, converting pixel positions into real-world distances in meters. This information is packaged into messages that tell the robot "there's a blue crate 1.2 meters ahead and 0.3 meters to the left" or "there's a pantry 2 meters in front." These messages can then be used by other parts of the robot to decide what to do next like driving toward a crate to pick it up or navigating to a pantry to place it.

The system is designed to work in real-time, processing every camera frame to keep track of objects as the robot moves around. It's smart enough to filter out noise (like small blobs that aren't real objects) and, for pantries, remembers which ones it's already seen to avoid counting the same pantry twice. All of this runs independently for crates and pantries, making it flexible and modular.

8. Technical Details

Computer Vision Techniques

Color Space Selection: HSV (Hue, Saturation, Value) is used instead of RGB because it's more robust to lighting variations. The hue channel isolates color independent of brightness.

Morphological Operations:

- Closing: Fills small holes in detected regions (kernel 5×5, 2 iterations for crates)
- Opening + Closing: Removes noise then fills gaps (pantry detection)

Distance Estimation: Uses the pinhole camera model:

distance = (real_object_width × focal_length_pixels) / object_width_pixels

This assumes the camera is calibrated and the object width is known.

Coordinate Transformation: Converts from camera-centric pixel coordinates to robot-relative Cartesian coordinates:

angle_rad = atan2(pixel_offset_from_center, focal_length)

robot_x = distance × cos(angle_rad) + camera_offset

robot_y = distance × sin(angle_rad)

Limitations

- Occlusion: Cannot detect objects blocked by others
- Lighting Sensitivity: HSV ranges may need adjustment for different environments
- Single Camera: No depth information, relies on geometric assumptions
- Color Uniqueness: Assumes target colors don't appear elsewhere in scene
- Scale Ambiguity: Distance estimation requires known object size

Appendix A: Package Structure

eurobot_perception/

├── package.xml

├── setup.py

├── resource/

│ └── eurobot_perception

├── eurobot_perception/

│ ├── __init__.py

│ ├── crate_perception.py

│ └── pantry_detection.py

└── test/

├── test_copyright.py

├── test_flake8.py

└── test_pep257.py

Appendix B: Dependencies Installation

# ROS 2 dependencies (should be installed with ros-humble-desktop)

sudo apt install ros-humble-sensor-msgs ros-humble-cv-bridge

# Python dependencies

pip3 install opencv-python numpy

# Custom interfaces (build from source)

cd ~/eurobot_ws/src

# Ensure eurobot_interfaces package exists

colcon build --packages-select eurobot_interfaces

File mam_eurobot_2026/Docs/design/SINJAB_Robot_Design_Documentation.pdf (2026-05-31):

### Robot Design Documentation – SINJAB

### 1. Introduction

The project 'SINJAB' is a circular robot designed with the primary goal of collecting nuts and delivering them to the nest. The design was created using SolidWorks and aims to provide efficient and stable movement while maintaining a compact structure.

### 2. Robot Specifications

Robot Name: SINJAB

Purpose: To get the nuts to the nest

CAD Software: SolidWorks

Shape and Dimensions: Circular robot with a diameter of 200 mm and a 100 mm parallel jaw grip

Main Components: Body, Wheels, Grip, Stem, Head

Material: 3D printed plastic (PLA)

Drive System: Two wheels with a caster for support

Mechanical Team Members: Hussein Youssef and Bashir Awad

### 3. Design Overview

The SINJAB robot was modeled in SolidWorks using a modular approach. The design consists of a main circular body housing the motors and electronics, a stem supporting the head and grip mechanism, and two driven wheels with a rear caster for balance.

### 4. Component Breakdown

- Body: The main structure that holds all components together.
- Wheels: Two driven wheels provide movement and are supported by a front caster.
- Grip: A 100 mm parallel jaw mechanism designed to pick up nuts.
- Stem: Connects the main body with the head and ensures stable lifting motion.
- Head: Contains sensors or visual components for detection and control.

### 5. Materials and Manufacturing

The entire robot structure is designed to be plastic material. This choice provides a lightweight, cost-effective, and easily replaceable structure suitable for prototyping and testing.

### 6. Drive System

SINJAB uses a differential drive system consisting of two powered wheels and one caster for stability. This setup allows the robot to move forward, backward, and rotate around its axis for precise navigation.

### 7. Conclusion

The SINJAB robot represents a compact and efficient design ideal for nut collection and delivery tasks. Its simple mechanical structure and 3D-printed build make it highly suitable for testing, improvement, and educational applications.

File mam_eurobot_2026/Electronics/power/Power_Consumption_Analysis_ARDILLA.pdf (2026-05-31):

# POWER CONSUMPTION ANALYSIS

## Robot Power & Distribution System

Team ARDILLA
Elsa OUMA | Martina ESQUIROZ
Document Revision: V1 — May 2026

## 1. Introduction

This document presents the complete power consumption analysis for the ARDILLA robot. Its purpose is to verify that the power architecture — based on two 11.1 V LiPo batteries — is correctly dimensioned to supply all electronic, computational, and mechanical subsystems safely and reliably.
The analysis covers all components listed in the Bill of Materials (BOM V2, May 2026). For each component, the operating voltage, typical current draw, and power consumption are stated. The document concludes with a full power budget summary, battery runtime estimates, and a fuse safety verification.

## 2. Methodology

Power consumption is calculated using Ohm's Law:
P (W) = V (V) × I (A)

Where P is power in Watts, V is the operating voltage, and I is the typical current drawn by the component. Values are taken from manufacturer datasheets or well-established community benchmarks where datasheets are not publicly available.
Three power rails are defined for this system:
- 12 V rail — directly from the LiPo battery pack via the XT60 connectors and 15A fuse. Supplies the drive motors and motor driver.
- 5 V rail — supplied by two step-down DC-DC converters (BOM #9). One converter powers the logic electronics (Horizon X3 Pi, RPLIDAR, Arduino Mega); the other is reserved for servo supply.
- 3.3 V rail — derived from the 5 V rail via the LD1117V33 LDO regulator on the Sensor/IO board. Supplies I2C sensors, ADC, and the ultrasonic module.

For runtime estimation, the 80% usable capacity rule is applied to the LiPo batteries, meaning only 80% of the total stored energy is used to protect battery chemistry and avoid deep discharge:
Runtime (h) = Usable Energy (Wh) ÷ Total Power (W)

## 3. Component Power Analysis

### 3.1 Power Source — LiPo Batteries (#4)

The robot is powered by two RS PRO LiPo batteries rated at 2.6 Ah and 11.1 V each, connected in parallel. This doubles the capacity while maintaining the nominal voltage.

Parameter | Value | Notes
Nominal voltage | 11.1 V | 3-cell LiPo (3 × 3.7 V)
Capacity per cell | 2.6 Ah | RS PRO specification
Total capacity (parallel) | 5.2 Ah | 2 × 2.6 Ah
Total energy | 57.7 Wh | 5.2 Ah × 11.1 V
Usable energy (80%) | 46.2 Wh | Safe discharge limit for LiPo

### 3.2 Drive Motors — RS PRO DC Gear Motor (#10, ×2)

Two RS PRO 12V DC gear motors (10 Ncm, 180 rpm, 5 mm shaft) provide traction. These are the dominant consumers in the power budget, driven through the DFRobot motor driver on the 12 V rail.

Parameter | Rail | Voltage (V) | Current (A) | Power (W)
Motor M1 — typical running | 12 V | 11.1 | 1.00 | 11.1
Motor M2 — typical running | 12 V | 11.1 | 1.00 | 11.1
Both motors — heavy load | 12 V | 11.1 | 2.00 each | 44.4
Both motors — stall (peak) | 12 V | 11.1 | 4.00 each | ~88.8

NOTE: Stall current should be avoided during normal operation. The 15A fuse protects against prolonged stall, but the motors themselves may overheat if held stalled for extended periods.

### 3.3 Motor Driver — DFRobot Dual-Channel 10A (#11)

The DFRobot DFR0601 dual-channel MOSFET-based motor driver provides up to 10A per channel, making it well-suited for these motors. It consumes a small amount of power itself through logic supply and switching losses.

Component | Rail | Voltage (V) | Current (A) | Power (W) | Notes
Driver logic (VCC) | 5 V | 5.0 | 0.05 | 0.25 | Control circuitry
MOSFET switching loss | 12 V | 11.1 | ~0.12 | ~1.3 | ~6% of motor load

### 3.4 Computing — Horizon X3 Pi (#1)

The Horizon RDK X3 (Sunrise X3 Pi) is the robot brain. It runs Ubuntu 20.04 and handles high-level decision making, AI inference (5 TOPS), sensor fusion, and communication. The official power specification requires a 5V/3A supply, and typical consumption under a robot workload is approximately 4.5 W.

Operating mode | Rail | Voltage (V) | Current (A) | Power (W)
Idle | 5 V | 5.0 | 0.60 | 3.0
Typical robot workload | 5 V | 5.0 | 0.90 | 4.5
Peak (AI inference + I/O) | 5 V | 5.0 | up to 1.50 | up to 7.5

### 3.5 Microcontroller — Arduino Mega 2560 R3 (#3)

The Arduino Mega 2560 R3 handles low-level control tasks including PWM signals to the motor driver and reading encoder feedback. It operates from the 5V logic rail and consumes minimal power.

Component | Rail | Voltage (V) | Current (A) | Power (W) | Notes
Arduino Mega 2560 R3 | 5 V | 5.0 | 0.15 | 0.75 | Board + active I/O

### 3.6 LIDAR Scanner — RPLIDAR A1 (#12)

The RPLIDAR A1 is a 360-degree 2D laser scanner used for localisation and obstacle detection. It draws approximately 700 mA at 5V during continuous scanning operation, as documented in the Slamtec datasheet.

Component | Rail | Voltage (V) | Current (A) | Power (W) | Notes
RPLIDAR A1 (scanning) | 5 V | 5.0 | 0.70 | 3.50 | Datasheet: ~700mA
RPLIDAR A1 (idle/motor off) | 5 V | 5.0 | 0.10 | 0.50 | Motor stopped

### 3.7 Camera — HBV-313 USB Camera (#13)

The HBV-313 is a USB camera module from HBVCAM, used for vision processing. Based on published power data from HBVCAM USB modules, it consumes approximately 150–200 mW during active imaging.

Component | Rail | Voltage (V) | Current (A) | Power (W) | Notes
HBV-313 camera (active) | 5 V | 5.0 | 0.04 | 0.20 | Via USB from X3 Pi

### 3.8 Servo Motor — JAMARA High-Torque Servo (#14, ×1)

One high-torque servo motor (4–6 V operating range) is used for mechanism actuation. The servo supply is provided by the second DC-DC converter (BOM #9), which is kept separate from the logic supply to prevent motor noise from resetting the X3 Pi.

Operating state | Rail | Voltage (V) | Current (A) | Power (W) | Notes
Servo — active / moving | 5 V | 5.0 | 0.50 | 2.50 | Under moderate load
Servo — holding position | 5 V | 5.0 | 0.10 | 0.50 | Static hold

### 3.9 DC-DC Converters (#9, ×2)

Two step-down (buck) DC-DC converters step the 11.1V battery voltage down to 5V. One supplies the logic and sensors, the other supplies the servo. Assuming 90% conversion efficiency, approximately 10% of the output power is lost as heat in each converter.

Converter | Input | Output | Load (W) | Loss at 90% eff. (W)
#9a — Logic supply (X3 Pi, RPLIDAR, Arduino, camera) | 11.1 V | 5 V | ~8.9 | ~0.99

#9b — Servo supply (JAMARA servo) | 11.1 V | 5 V | ~2.5 | ~0.28

DESIGN NOTE: Using two separate converters for logic and servo power is good practice. Servo motors generate voltage spikes when reversing direction, which can interfere with sensitive logic. Separate rails provide isolation.

### 3.10 Sensor & I/O Board Components

The Sensor/IO board (from the KiCad schematic) contains several low-power ICs running on the 3.3V rail. These collectively represent a negligible fraction of the total power budget.

Component | Rail | Voltage (V) | Current
(mA) | Power (W) | Function
LD1117V33 LDO (U4) — heat loss | 5V→3.3V | — | — | 0.85 | (5-3.3V)×0.5A wasted
TCA9548A I2C multiplexer (U2) | 3.3 V | 3.3 | 5 | 0.016 | I2C bus routing
ADS1115 16-bit ADC (U3) | 3.3 V | 3.3 | 0.15 | 0.0005 | Analog readings
INA219 current monitor | 5 V | 5.0 | 1 | 0.005 | 12V rail monitoring
Ultrasonic sensor (J2) | 3.3 V | 3.3 | 15 | 0.050 | Distance sensing
Limit switches ×2 (#15) | 3.3 V | 3.3 | ~1 | 0.003 | End-stop detection
SD Card (#2) | 5 V | 3.3 | 50 | 0.15 | Via X3 Pi internally

### 3.11 Passive Components (Switches, Fuse, Connectors)

The main ON/OFF switch (#5), emergency stop button (#6), ATC fuse and holder (#7), and XT60 connectors (#8) are all passive components that carry current but consume no power themselves in normal operation.

FUSE NOTE: The 15A slow-blow ATC fuse (#7) is correctly rated. At typical operation (~4A from the battery), it provides a 3.75× safety margin. It will only blow in the event of a short circuit or sustained overcurrent above 15A.

## 4. Complete Power Budget Summary

The following table consolidates the power consumption of all BOM components across the three power rails. Values are for typical operating conditions with both motors running at moderate speed.

# | Component | Rail | V (V) | I (A) | P typical

(W) P peak (W)
1 | Horizon X3 Pi | 5 V | 5.0 | 0.90 | 4.50 | 7.50
2 | SanDisk SD Card 64GB | 5 V | 3.3 | 0.05 | 0.15 | 0.20
3 | Arduino Mega 2560 R3 | 5 V | 5.0 | 0.15 | 0.75 | 0.80
4 | LiPo Batteries ×2 | — | 11.1 | — | Source | Source
5 | Main ON/OFF Switch | 12 V | — | ~0 | ~0 | ~0
6 | Emergency Stop Button | 12 V | — | ~0 | ~0 | ~0
7 | Fuse + Holder (15A) | 12 V | — | ~0 | ~0 | ~0
8 | XT60 Connectors | 12 V | — | ~0 | ~0 | ~0
9a | DC-DC Converter (logic) loss | 12 V | 11.1 | ~0.09 | 0.99 | 1.30
9b | DC-DC Converter (servo) loss | 12 V | 11.1 | ~0.03 | 0.28 | 0.40
10 | RS PRO DC Gear Motors ×2 | 12 V | 11.1 | 1.00 ea. | 22.20 | 88.80
11 | DFRobot Motor Driver (10A) | 5V+12V | — | — | 1.55 | 2.00
12 | RPLIDAR A1 | 5 V | 5.0 | 0.70 | 3.50 | 3.50
13 | HBV-313 USB Camera | 5 V | 5.0 | 0.04 | 0.20 | 0.25
14 | JAMARA Servo Motor ×1 | 5 V | 5.0 | 0.50 | 2.50 | 3.00
15 | Limit Switches ×2 | 3.3 V | 3.3 | ~0.001 | ~0 | ~0
— | Sensor/IO board ICs | 3.3 V | 3.3 | ~0.02 | ~0.15 | 0.20
| TOTAL | All | — | — | ~36.8 W | ~108 W

### 4.1 Power by Rail

Rail | Typical Power (W) | Peak Power (W) | Supplied by
12 V (motors + driver) | ~24.0 | ~90.8 | LiPo batteries directly
5 V (logic + sensors + servo) | ~12.6 | ~16.2 | 2× DC-DC step-down converters
3.3 V (I2C sensors, ADC) | ~0.15 | ~0.20 | LD1117V33 on Sensor/IO board
TOTAL | ~36.8 W | ~108 W

## 5. Battery Runtime Estimation

Using the usable energy of 46.2 Wh (80% of 57.7 Wh total), the estimated battery runtime under three representative operational scenarios is:

Scenario | Total Power (W) | Estimated
Runtime | Description
Electronics only (no motors) | ~6.0 W | ~7.7 hours | X3 Pi + sensors idle, motors off
Normal operation | ~36.8 W | ~1.25 hours | Both motors at moderate speed, all sensors active
Heavy load | ~55.0 W | ~0.84 hours | Motors under high load, all systems active
Peak / stall (brief) | ~108 W | ~0.43 hours | Should not be sustained — fuse protection active

For a competitive robotics context, a runtime of approximately 1.25 hours under normal operating conditions is adequate for extended testing and multiple runs. The two batteries in parallel provide both the capacity and current capability required.

## 6. Protection and Safety Verification

### 6.1 Fuse Check — ATC 15A Slow-Blow (#7)

Scenario | Battery current draw (A) | Status
Electronics only (no motors) | ~0.54 A | Safe (3% of fuse rating)
Normal driving (both motors) | ~3.8 A | Safe (25% of fuse rating)
Both motors heavy load | ~5.0 A | Safe (33% of fuse rating)
Both motors stalled (peak) | ~9.7 A | Safe (65% of rating) — avoid prolonged stall
Short circuit | > 15 A | Fuse blows — circuit protected

CONCLUSION: The 15A slow-blow fuse is correctly specified. Under all normal operating scenarios, the current draw is well within the fuse rating, providing appropriate protection without nuisance tripping.

### 6.2 DC-DC Converter Sizing

The two DC-DC converters must be sized for the maximum 5V load they will supply:
- Logic converter (#9a): Max load = X3 Pi (1.5A peak) + Arduino (0.15A) + RPLIDAR (0.7A) + Camera (0.04A) = ~2.4A. A converter rated at 3A minimum is required.
- Servo converter (#9b): Max load = 1 servo (0.5A typical, up to 1A peak) = 1A. A converter rated at 2A minimum is sufficient.

## 7. Conclusions

The power architecture of the ARDILLA robot is correctly dimensioned for the components defined in BOM V2 (May 2026). The key conclusions are:
- Total typical power consumption is approximately 36.8 W, dominated by the two 12V drive motors (60% of budget).
- The two LiPo batteries in parallel (57.7 Wh total, 46.2 Wh usable) provide an estimated runtime of approximately 1.25 hours under normal conditions.
- The 15A slow-blow fuse provides adequate circuit protection across all operating scenarios.
- The two DC-DC converters correctly replace the LM7805 LDO and are necessary to supply the X3 Pi and servo with sufficient current.
- Keeping the servo on a separate 5V rail from the logic electronics is good engineering practice and eliminates potential noise-induced resets.
- The Sensor/IO board (3.3V rail) consumes a negligible fraction (<0.5%) of the total power budget.

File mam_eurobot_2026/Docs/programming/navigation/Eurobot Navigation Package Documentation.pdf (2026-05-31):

Eurobot Navigation Package Documentation

### 1. Package Overview

### 1.1 High-Level Goal

The eurobot_navigation package provides the complete navigation stack and mission control system for the Eurobot autonomous robot. It enables the robot to:

- Map its environment using SLAM (Simultaneous Localization and Mapping)
- Localize itself within a known map using AMCL (Adaptive Monte Carlo Localization)
- Plan collision-free paths from current position to goal positions
- Execute smooth trajectory tracking with dynamic obstacle avoidance
- Coordinate high-level mission logic to collect crates and deliver them to pantries
- Integrate perception data to build and maintain a world model
- Make decisions autonomously based on task priorities and robot state

### 1.2 System Architecture

The package consists of five main components working together:

1. SLAM Node - Builds maps from LiDAR data during exploration
2. Localization Node - Estimates robot pose within known maps
3. Global Planner - Computes optimal paths avoiding static obstacles
4. Local Planner - Executes trajectory tracking with real-time obstacle avoidance
5. Task Manager - High-level mission coordinator that orchestrates the entire system

These components wrap and integrate standard ROS 2 Nav2 tools (slam_toolbox, AMCL, planner_server, controller_server) with custom mission logic designed specifically for the Eurobot competition.
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

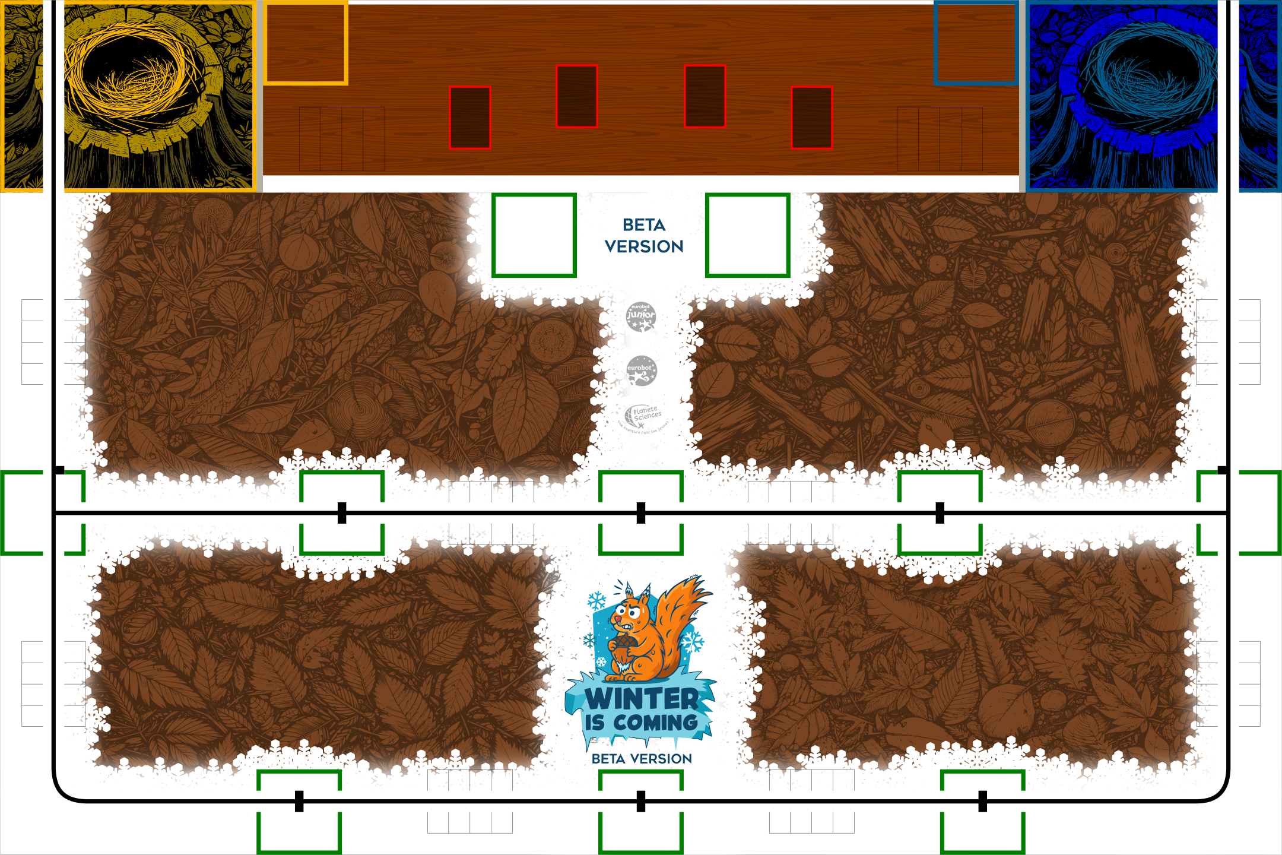
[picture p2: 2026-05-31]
src/mam_eurobot_2026/models/mat/mat_small.png

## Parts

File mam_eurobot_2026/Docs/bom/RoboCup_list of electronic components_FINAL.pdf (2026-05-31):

Here’s a clean Bill of Materials (BOM) for a 2-wheel main robot + 1 SIMA, with quantities and the reason/purpose for each choice.

Bill of Materials — Eurobot MVP (Main Robot + 1 SIMA)

1) Power & Protection (Main Robot)
Qty | Item | Spec | Reason/Purpose | Notes

1

Main battery
pack

8S LiFePO₄ ≈ 25.6
V, 5–10 Ah (CE)

24 V headroom for
torque; safer chemistry

24 V architecture
> 12.8 V from
PDF.
1 | DC-DC buck | 24 V→5 V, ≥ 5 A | Stable logic/sensor rail | Adjustable module
| | | | OK
1 | DC-DC buck | 24 V→12 V, ≥ 5 A | Servos/LEDs rail if
| | | needed | Optional (can use
| | | | 6–7.4 V BEC
| | | | instead)
1 | Main fuse +
| holder | 25–30 A automotive | Protects main feed | Close to battery

1

Per-driver

fuse | 15–20 A blade | Protects motor branch | Size to stall current

1

E-stop (NC

| mushroom) | Panel mount | Cuts motor power only | Logic stays on to halt safely
1 | Power switch | High-current | Convenience & safety | Upstream of distribution
1 | Panel
voltmeter | 5–60 V | Battery monitoring | Avoid over-
| | | discharge

4

XT60/XT90

pairs | High-current | Safe, polarized power
| | links | Main + branches

1
set Wiring kit

Silicone AWG14–18
(power), AWG22–
26 (signal)

Reliable wiring Include ferrules & heat-shrink

1

Distribution

board/PCB | Custom or prefab | Neat power branching | Mount fuses & bucks

2) Compute & Control

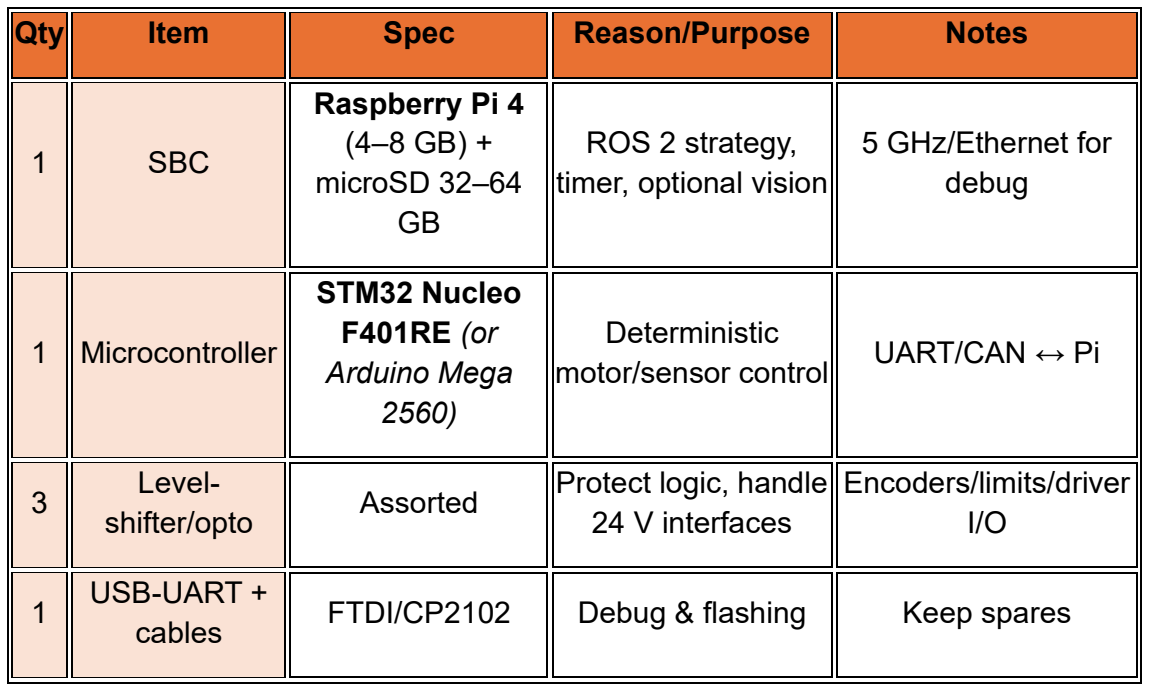
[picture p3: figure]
Qty; Item; Spec; Reason/Purpose; Notes; SBC; Raspberry Pi 4 (4–8 GB) + microSD 32–64 GB; ROS 2 strategy, timer, optional vision; 5 GHz/Ethernet for debug; Microcontroller; STM32 Nucleo F401RE (or Arduino Mega 2560); Deterministic; motor/sensor control; UART/CAN ↔ Pi; Level-; 24 V interfaces; Encoders/limits/driver I/O; USB-UART +

shifter/opto | Assorted | Protect logic, handle
cables | FTDI/CP2102 | Debug & flashing | Keep spares
3) Drive & Actuation (Main Robot)

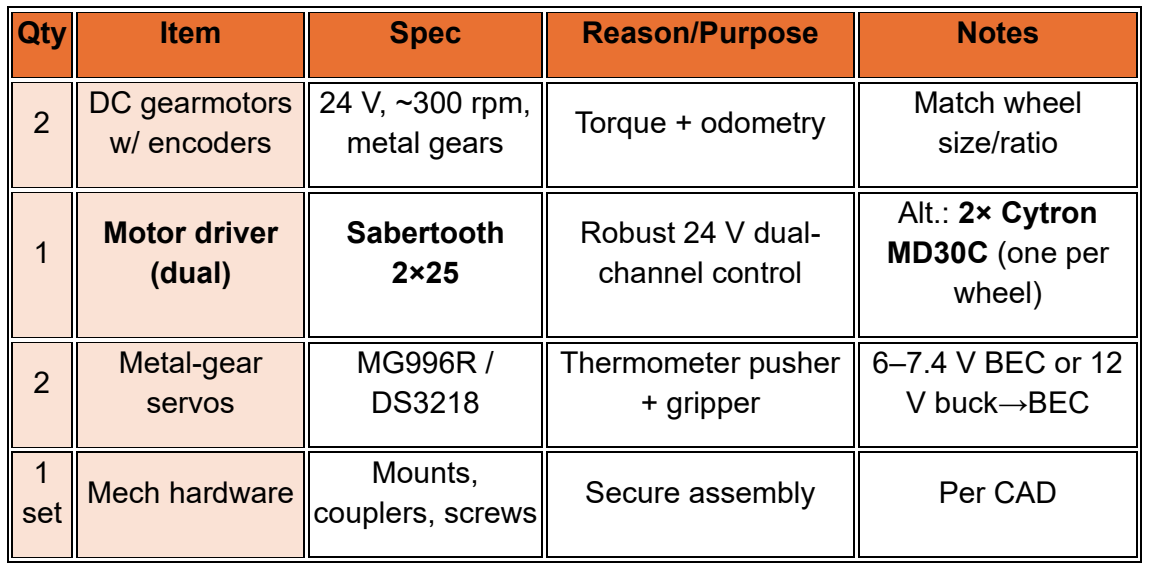
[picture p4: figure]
Qty; Item; Spec; Reason/Purpose; Notes; DC gearmotors w/ encoders; 24 V, ~300 rpm,; size/ratio; Motor driver (dual); Sabertooth 2×25; Robust 24 V dual- channel control; Alt.: 2× Cytron MD30C (one per wheel); Metal-gear servos; Thermometer pusher + gripper; 6–7.4 V BEC or 12 V buck→BEC; set; Mech hardware; Mounts,

metal gears | Torque + odometry | Match wheel
couplers, screws | Secure assembly | Per CAD

Why not TB6612FNG/L298N for main drive? They’re undersized for 24 V & higher torque; keep them for SIMA only. The DOC’s higher-current driver approach is safer/more reliable.

4) Sensors (Main Robot — MVP stack)

Qty | Item | Spec | Reason/Purpose | Notes
1 | IMU | BNO055 /
| | MPU6050 | Heading & pose
| | | stabilization | I²C

5

ToF distance
sensors

VL53L0X/L1X Obstacle/wall distance, alignment

Front L/C/R + two
sides

1

Reflectance
array

QTR-8A /
TCRT5000 bar

Edge/line detection near
nest/thermo | Analog/digital
3 | Limit switches | Lever microswitch

Gripper present / end-
stops | NO/NC as needed

1

(Opt.) Color
sensor
| | TCS34725 | Confirm team-color
| | | crate at pickup | Mount near gripper
1 | (Opt.) Camera | Pi Cam v2 / USB | Future ArUco/vision | Phase 2 upgrade
— | (Deferred)
| LiDAR | — | Not needed for MVP on
| | | 3×2 m field | Add only if tests
| | | | show blocking
5) Safety & UI

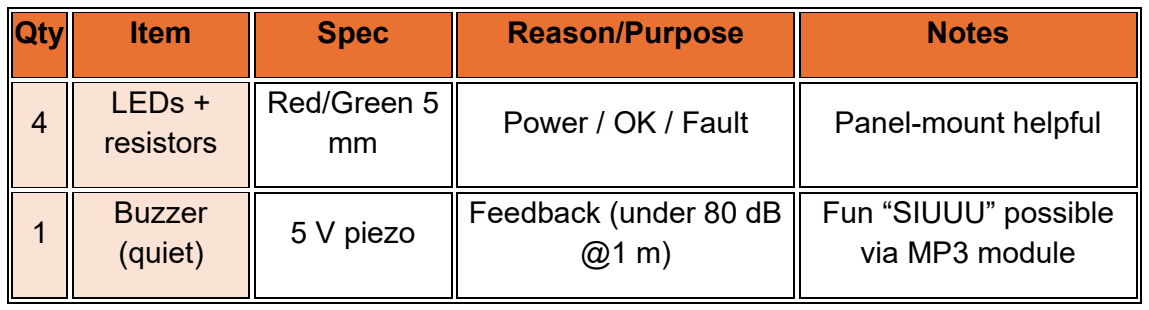
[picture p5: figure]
Qty; Item; Spec; Reason/Purpose; Notes; LEDs + resistors; Red/Green 5 mm; Power / OK / Fault; Panel-mount helpful; Buzzer; (quiet); 5 V piezo; Feedback (under 80 dB; Fun “SIUUU” possible via MP3 module

6) SIMA (Phase 2 add-on)
Qty | Item | Spec | Reason/Purpose | Notes
1 | MCU | Arduino Nano (or STM32
| | F103 “Blue Pill”) | Simple autonomy | Lightweight
1 | Motor driver | TB6612FNG | Dual small motors | Efficient vs
| | | | L298N
2 | Mini DC
| gearmotors | 6–12 V | SIMA propulsion | Low current

Qty | Item | Spec | Reason/Purpose | Notes
1 | Battery | 2S–3S Li-ion/LiFePO₄ | SIMA power | Switch + JST
1 | ToF / line
| sensor | VL53L0X or line module | Simple nav | Front mount
1 | Micro-servo | SG90 | “Eating”
| | | animation | End of match

1

Power switch +
LED | Mini toggle + LED | On/Off + status | —

Why this BOM (in one breath)

- 24 V LiFePO₄ + robust drivers → torque headroom, lower currents, reliability (DOC).
- Pi 4 + MCU split → ROS 2 on SBC; deterministic I/O on MCU (both files align here).
- IMU + ToF + reflectance + limits → MVP-ready sensing without LiDAR; camera optional (PDF listed LiDAR; we defer).
- SIMA with TB6612FNG → right scale driver for tiny actuators (keep heavy drivers for main robot).

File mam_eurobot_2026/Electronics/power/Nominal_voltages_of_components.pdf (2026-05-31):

1

# Specificationsfornominalvoltagesofcomponents

### 1. Voltagesinvolvedandtheirvalues (the power supply rails)

Inourrobot,weprimarilyusetwodistinctvoltagelevels,eachwithaspecific role (hencethe needtodesignapowerdistributionboardPCB):

Tension (rail) | Nominal Value | Role | Source on PCB
High voltage | 12V (between 11.1V and 12.8V) | Power and movement. Powers all components requiring mechanical energy: traction motor (J4, J5) and the UBEC converter (J2) | Directly to the battery (after fuse FH1 and switch SW1)
Low voltage | 5V | Logic and Control. Powers the sensitive electronics (the "brain" of the robot): Raspberry Pi 4, Arduino Mega 2560, and most Sensors/Servos. | The External UBEC (which converts 12V to 5V), returning to J3

### A. Componentsonthe12Vrail(power)

Component | Nominal Voltage | Role on the Robot | Connector on the PDB
DC motor with encoder (x2) | 12V | Traction (motion) motors | J4 and J5
TB6612FNG motor driver (x2) | 5V (Logic) s 12V (Power) | The driver requires 12V to power the motors themselves (V-Motor) and 5V for its own internal logic. | J6 (To 12V or direct wiring if the driver is remote)
UBEC 5V 5A (External) | 12V (input) | DC-DC converter (takes 12V and outputs 5V). | J2 (In UBEC)

2

### A. Components on the 5V rail (logic)

Component | Nominal Voltage | Role on the Robot
Raspberry Pi 4 Model B (8 GB) | 5V | Robot brain (vision, ROS2, planning).
Arduino Mega 2560 R3 | 5V (USB ou broche VCC) | Microcontroller (low-level control of motors and sensors).
Servomotor (x2) | 4.8 à 6V | Movements of the mechanisms.
Sensors (Distance, Line, etc.) | Typically, 5V or 3.3V | Perception of the environment.
MicroSD card | Powered by the RPi (3.3V regulated) | Raspberry Pi storage.
TB6612FNG | 5V(logic) | Motor control logic.

### 2. Calculation of Estimated Total Power

Power (in Watts, W) is calculated by the formula: P = U / I (Voltage /Current).

Component | Voltage (U) | Estimated Current (Imax) | Power (P=U×I)
DC motors (x2) | 12V | ≈2x3 A continuous (5A peak) | ≈60W (peak start-up)
UBEC (12V Input) | 12V | 5A (5V output) → ≈2.5A (12V input) | ≈30W (at 12V)
Motor Drivers (TB6612) | 12V | ≈0.5A | ≈6W
Estimated Total (Crest) | | | ≈96W

### Detailed Hypotheses

a. Traction Motors: DC motors, even though they draw 1A continuously, can draw up to 5A or 6A each during startup or when encountering an obstacle (stall current). We estimate here 5A per motor peak, or 10A for both.
P_motors = 12V x 10 A = 120W (We will use the total of 120W for the fuse calculation, as this is the worst-case scenario.)
b. UBEC (Converter):
- The UBEC delivers 5V with a maximum of 5A (i.e., 25W at 5V).

3

- Assuming a conversion efficiency of 85%, the current drawn at 12V is:

I_ubec ≈

Psortie
UentréeX Efficacité

≈

25W
12V X 0.85 ≈ 2. 45A
c. Other 12V (Drivers): The TB6612FNG drivers consume a small current for the power circuit, estimate 0.5A.

### Calculation of the Total Maximum Current

I_tot(crete) = I_moteurs(crete) + I_ubec(crete) + I_drivers I_tot(crete) = 10A+2.5A+0.5A=13A

### Consequences for the PDB

- Fuse (FH1): The maximum current of 13 A amply justifies the choice of a 10A fuse if we only wish to protect stable continuous regimes (where the current does not exceed 6-8A).

### Conclusion

The maximum total power our robot can draw from the battery is approximately 156W (12V x 13A) at startup. Our PDB (Power Distribution Board) is designed to handle this high power.

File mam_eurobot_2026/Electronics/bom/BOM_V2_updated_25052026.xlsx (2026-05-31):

No. | Component | Details | Brand | Qty | Purpose | Vendor | Availability
1 | Horizon X3 Pi | Single-board computer (5V supply) |  | 1 | Robot Brain |  | Yes
2 | SanDisk SD Card 64GB | High-speed storage (A2 class) | SanDisk | 1 | OS and Storage |  | Yes
3 | Arduino Mega 2560 R3 | Microcontroller board (5V Logic) | Arduino | 1 | Low-level control (motors, sensors) | https://fr.farnell.com/arduino (https://fr.farnell.com/arduino/a000067/arduino-mega2560-rev3-carte/dp/2212779?gross_price=true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) | Yes
4 | LiPo Battery | 2.6 Ah, 11.1V | RS PRO | 2 | Main Power Supply | https://fr.rs-online.com (https://fr.rs-online.com/web/p/blocs-batteries-rechargeables/1449413) | Yes
5 | Main ON/OFF Switch | Panel-mount SPST Switch | RS PRO | 1 | Power Control | https://fr.rs-online.com (https://fr.rs-online.com/web/p/interrupteurs-a-bascule/1858225)
6 | Emergency stop button | Latching safety switch | RS PRO | 1 | Emergency shutdown | https://fr.rs-online.com (https://fr.rs-online.com/web/p/boutons-d-arret-d-urgence/0102713)
7 | Fuse + Holder | ATC fuse holder (10A slow-blow) | RS PRO | 1 | Circuit protection | ATC-10 | Fusible automobile Eaton 10A, Rouge, 32V c.c. | RS (https://fr.rs-online.com/web/p/fusibles-automobiles/8482558)
8 | XT60 Connectors | High-current DC connectors | RS PRO | 2 | Power connection | https://fr.rs-online.com (https://fr.rs-online.com/web/p/connecteurs-de-puissance-compacts/1805360)
9 | DC-DC Converter | Step-down regulator | Reichelt | 2 | Logic supply | https://www.reichelt.com (https://www.reichelt.com/fr/fr/shop/produit/cartes_de_developpement_-_regulateurs_de_tension_convertisseurs-333855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) | Yes
10 | RS PRO DC Gear Motor | 12V DC, 10Ncm, 180 rpm, 5mm Shaft diameter | RS PRO | 2 | Traction | https://befr.rs-online.com (https://befr.rs-online.com/web/p/dc-motors/2588287) | Yes
11 | Motor Driver | Dual-channel driver (10A) | DFRobot | 1 | Motor control | https://www.mouser.fr (https://www.mouser.fr/ProductDetail/DFRobot/DRI0050?qs=Rp5uXu7WBW%252B%252BnOISV%252BWl7w%3D%3D)
12 | RPLIDAR A1 | 360 laser scanner) | Adafruit | 1 | Localization | https://www.mouser.fr (https://www.mouser.fr/ProductDetail/Adafruit/4010?qs=0lSvoLzn4L%2FnUZl0PALicA%3D%3D) | Yes
13 | HBV 313 | CSI camera module | Unknown | 1 | Vision |  | Yes
14 | Servo motors | High-torque servo (4-6V) | JAMARA | 1 | Mechanism actuation | https://www.reichelt.com/fr (https://www.reichelt.com/fr/fr/shop/produit/servo_high_end_micro_analogique-238316?PROVID=2810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) | Yes
15 | Limit Switch | Mechanical switch | RS PRO | 2 | End-stop detection | https://fr.rs-online.com (https://fr.rs-online.com/web/p/microrupteurs/8046259)
16 | 90 degree angle | mechanical part | BLAISE | 6 | Mechanical structure

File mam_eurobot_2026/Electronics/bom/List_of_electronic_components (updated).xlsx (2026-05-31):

Component | Reference / Specification | Availability in the laboratory | Note | Quantity | Links
Raspberry Pi 4 Model B (8 GB) | RPI4-MODBP-8GB | ✕ | Robot brain (for vision, planning, ROS2) | 1 | https://uk.rs-online.com/web/p/raspberry-pi/1822098
SanDisk Extreme 64GB A1 microSD Card | SDSQXA2-064G-GN6MA | ✕ | Raspberry Pi OS Storage | 1 | https://fr.rs-online.com/web/c/informatique-et-peripheriques/memoire-et-stockage-de-donnees/cartes-sd/
Arduino Mega 2560 R3 | A000067 | ✕ | Microcontroller for low level control (motors, sensors) | 1 | https://www.gotronic.fr/art-arduino-mega-2560-a000067-12421.htm
UBEC 5V 5A (Switching Regulator) | HW-UBEC-5V5A | ✓ |  | 1
DC Motor with Encoder | 12V, 200 RPM, 5 kg·cm | ✓ | Traction motor for right and left wheel | 2 | https://fr.rs-online.com/web/p/moteurs-a-courant-continu/0420697
TB6612FNG Motor Driver | Breakout Pololu/Sparkfun | ✕ | controls DC motors from Arduino | 1 | https://befr.rs-online.com/web/p/power-motor-robotics-development-tools/1887093
Wheels Ø 65 mm | D-shaft | ✕ | Main wheels for the motors (non-slip rubber), adapted hub | 2 | https://www.gotronic.fr/art-kit-moteurs-roues-encodeur-rs034-21383.htm
ball caster | Ø 25 mm | ✕ | Stabilizes the robot (multidirectional wheel) | 1 | https://www.pololu.com/product/2692
LiFePO₄ Battery | 12.8 V 6 Ah with BMS | ✕ | Main power supply of the robot | 1 | https://eu.mouser.com/ProductDetail/Ultralife/URB1270?qs=hNud%2FORuBR0MsB3YDGqcEQ%3D%3D
UBEC 5V 3A / 5A | HW-UBEC | ✓ | Regulator for raspberry pi and servo | 2 | DollaTek Module de Puissance DC-DC régulateur abaisseur 3A réglable 5V/12V/24V : Amazon.fr: Commerce, Industrie et Science (https://www.amazon.fr/DollaTek-LM2596S-ADJ-Puissance-r%C3%A9gulateur-abaisseur/dp/B07DJX97MS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)
Main ON/OFF Switch | Rocker 12V 10A | ✕ |  | 1 | https://fr.rs-online.com/web/p/interrupteurs-a-bascule/1858229
10A Fuse + ATC Fuse Holder | Standard automotive | ✕ | Short circuit protection | 1 | https://fr.rs-online.com/web/p/fusibles-automobiles/0563744
XT60 Connectors (M/F) | XT60 | ✕ | battery-power supply board connection | 2
Silicone Wires | AWG18–22 | ✓
Terminal Block / Power Distribution Board | Distribution | ✓ | Proper distribution of power supply | 1
RPLIDAR A1 (Slamtec) | 360° Laser Rangefinder | ✕ | 360° laser rangefinder for obstacle detection and location | 1 | https://www.slamtec.com/en/lidar/a1
BNO055 IMU (Bosch) | 9DOF with sensor fusion | ✕ | Inertial sensor (orientation, tilt) | 1 | https://www.adafruit.com/product/2472
TCS34725 Color Sensor | RGB + Clear + IR filtre | ✕ | For the detection of ground markers/zone colors | 1 | https://www.adafruit.com/product/1334
HC-SR04 Ultrasonic Sensor | 2–400 cm | ✕ | nearby object detection | 3 | https://www.gotronic.fr/art-module-de-detection-us-hc-sr04-20912.htm
Raspberry Pi Camera V2 | 8 MP Sony IMX219 | ✕ | Advanced vision/object recognition | 1 | https://fr.rs-online.com/web/p/cameras-pour-raspberry-pi/0219259
DS3218 Servo Motor (or MG996R) | Métal, 20 kg·cm | ✓ | Main clamp or lever | 3 | https://fr.rs-online.com/web/p/servomoteurs/7813058
Limit Switch | Mechanical limit detection | ✕ |  | 2 | https://www.mouser.fr/ProductDetail/Honeywell/NGCMB10AX01A1B
Emergency Stop Button (mushroom) | 22 mm, NC/NO | ✕ | Total power cut | 1 | https://fr.rs-online.com/web/p/boutons-d-arret-d-urgence/7452442
USB-UART Converter | CP2102 ou FT232RL | ✕ | PC-Arduino connection for debugging | 1 | https://fr.rs-online.com/web/p/accessoires-pour-outils-de-developpement/0429307?gb=a
Dupont Jumper Wires (M/F) | 120 pcs, 10–30 cm | ✓ | Assembly and prototyping |  | https://befr.rs-online.com/web/c/esd-control-cleanroom-pcb-prototyping/prototyping-boards/breadboard-jumper-wires/
JST/Molex Connectors | JST-XH 2.54 mm | ✓ |  | 1 | https://fr.rs-online.com/web/c/connecteurs/boitiers-et-connecteurs-pour-circuits-imprimes/embases-circuits-imprimes/

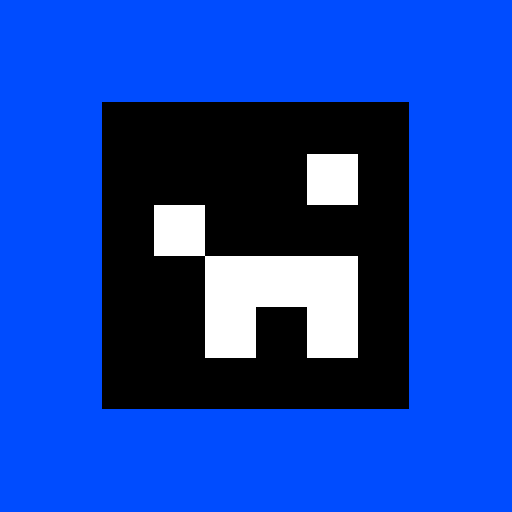
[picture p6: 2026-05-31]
src/mam_eurobot_2026/models/crate_yellow/materials/textures/aruco_blue_36.png

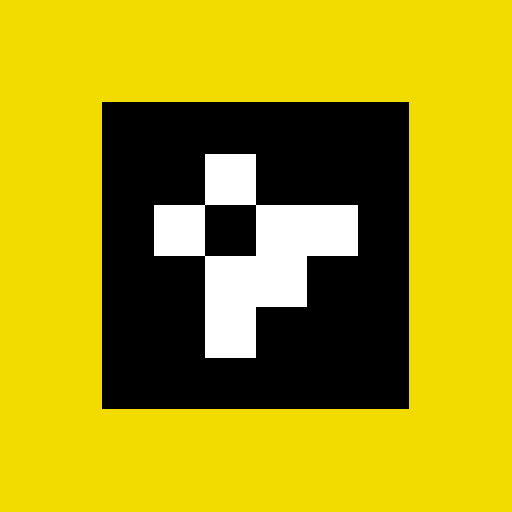
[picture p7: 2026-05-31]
src/mam_eurobot_2026/models/crate_yellow/materials/textures/aruco_yellow_47.png

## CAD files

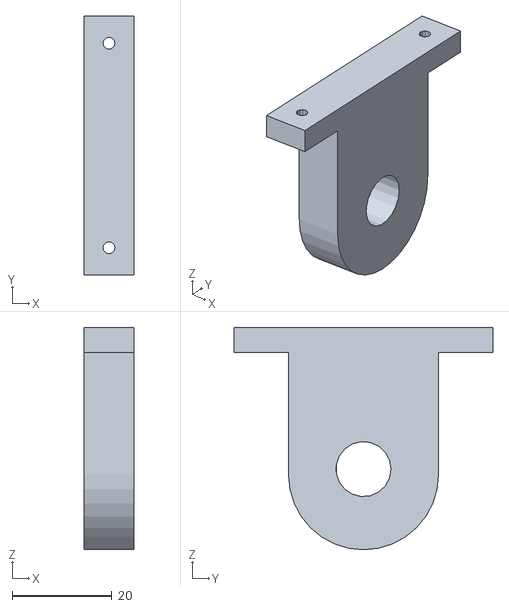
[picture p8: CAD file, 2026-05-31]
mam_eurobot_2026/Mechanical/Robot part/garf.STL
10.0 x 51.8 x 44.5

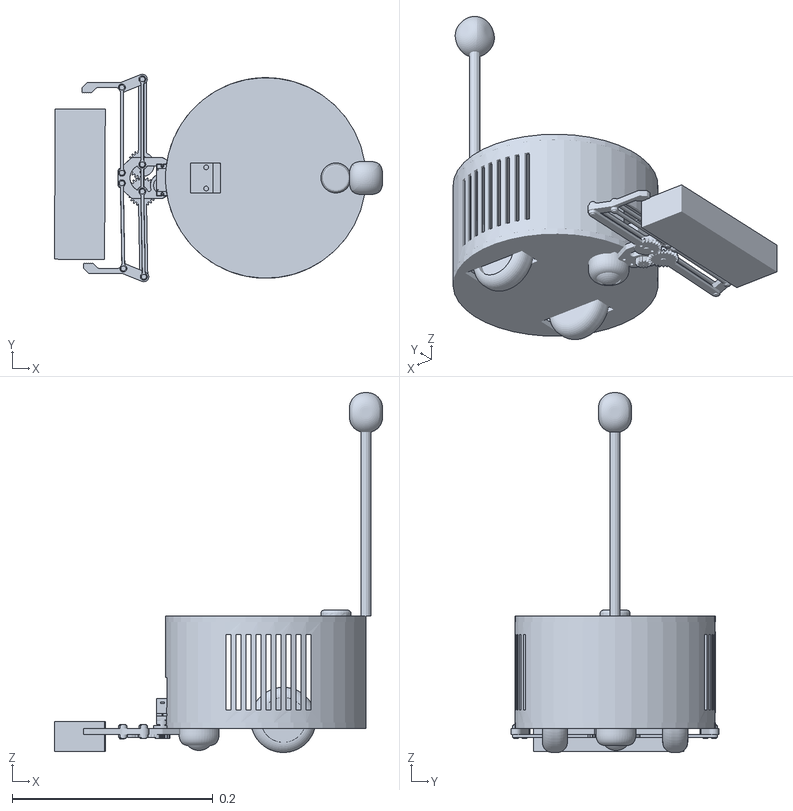
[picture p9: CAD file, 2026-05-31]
src/mam_eurobot_2026/meshes/Gripper.STL
0.327 x 0.207 x 0.359

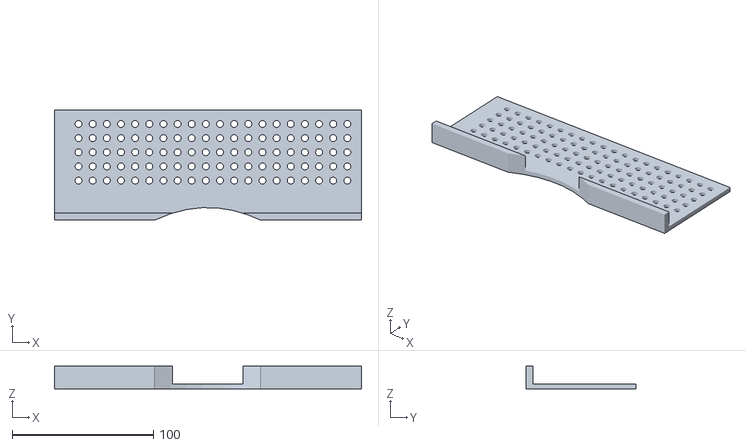
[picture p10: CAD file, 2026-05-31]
mam_eurobot_2026/Mechanical/Robot part/couvgauc.STL
217.0 x 78.0 x 16.0

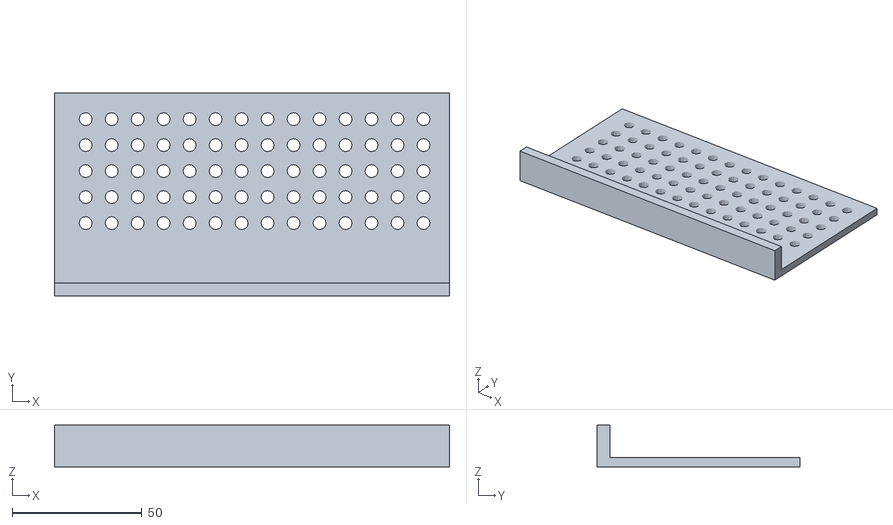
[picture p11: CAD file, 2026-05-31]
mam_eurobot_2026/Mechanical/Robot part/suppdroit.STL
152.0 x 78.0 x 16.0

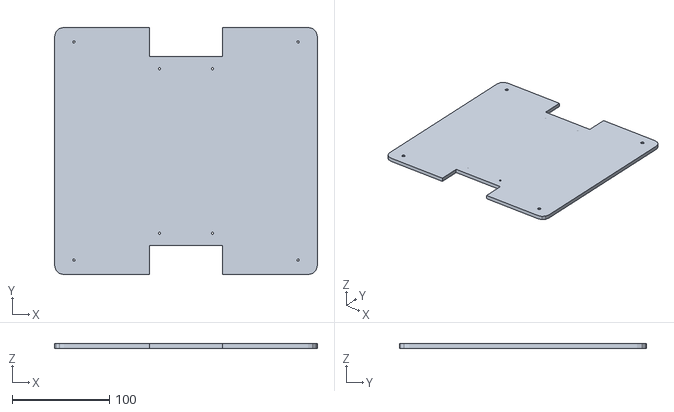
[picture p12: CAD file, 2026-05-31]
mam_eurobot_2026/Mechanical/Robot part/Plaquebass.STL
270.0 x 254.0 x 5.00

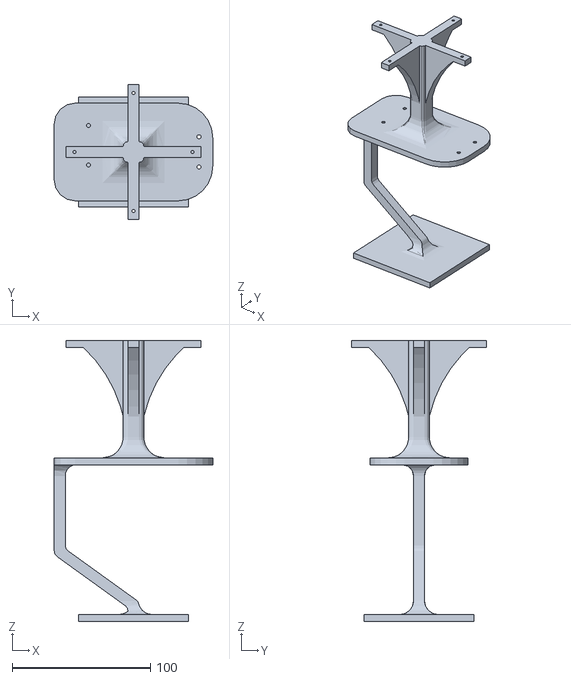
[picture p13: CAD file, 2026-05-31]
mam_eurobot_2026/Mechanical/Robot part/suppbalise.STL
114.8 x 97.7 x 203.5

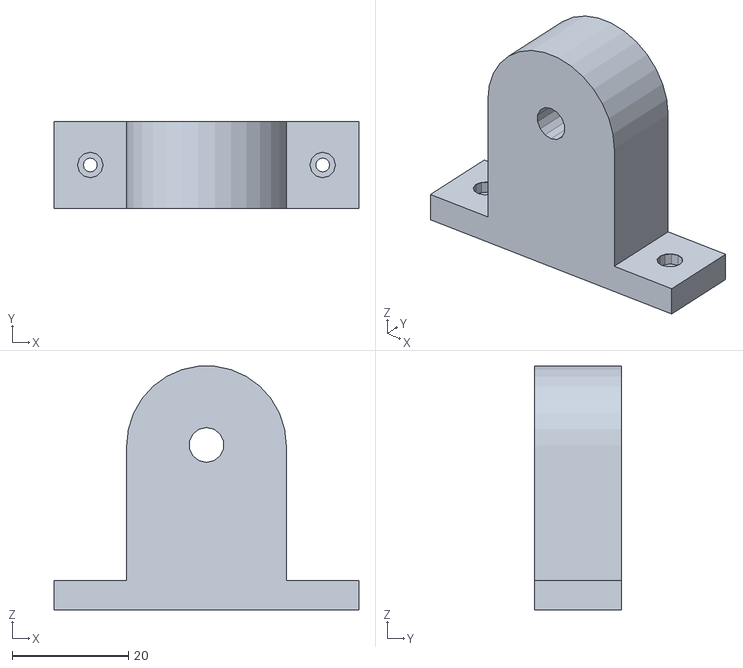
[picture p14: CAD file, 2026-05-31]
mam_eurobot_2026/Mechanical/Robot part/garfaxe.STL
52.5 x 15.0 x 41.9

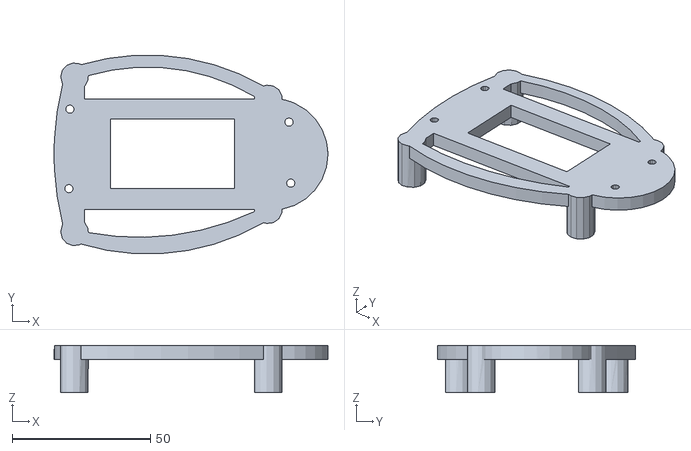
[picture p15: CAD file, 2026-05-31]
mam_eurobot_2026/Mechanical/Robot part/Part22.STL
98.9 x 71.6 x 17.0

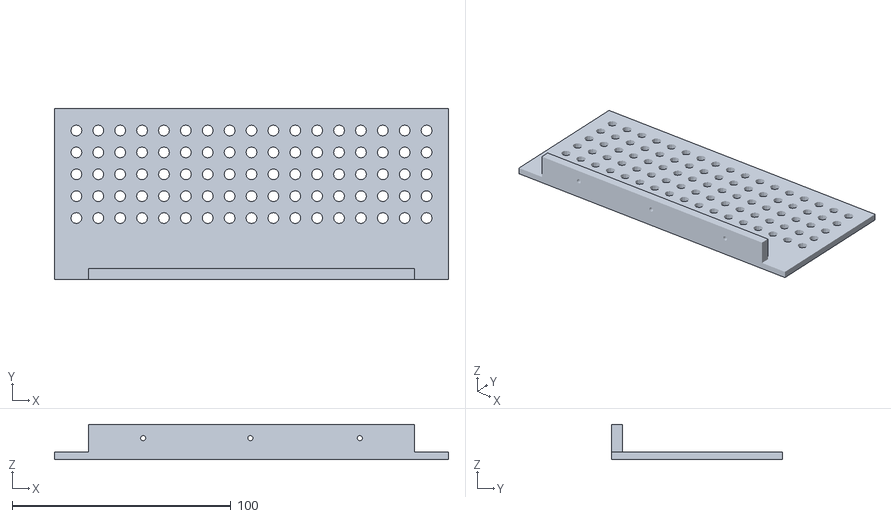
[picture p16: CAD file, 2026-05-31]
mam_eurobot_2026/Mechanical/Robot part/suppderri.STL
180.0 x 78.0 x 16.0

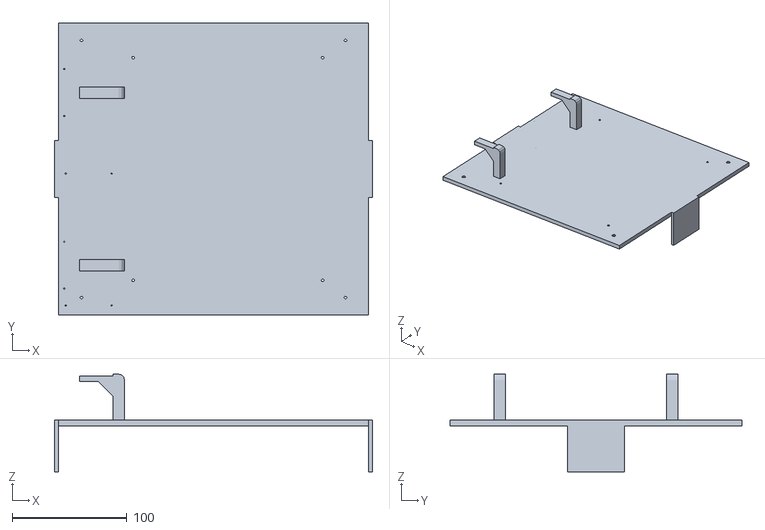
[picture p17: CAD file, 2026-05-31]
mam_eurobot_2026/Mechanical/Robot part/Plaque.STL
277.0 x 254.0 x 85.0

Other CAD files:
mam_eurobot_2026/Mechanical/Robot part/3_barre_support.STL
mam_eurobot_2026/Mechanical/Robot part/Plaquedessus.STL
mam_eurobot_2026/Mechanical/Robot part/couvdeva.STL
mam_eurobot_2026/Mechanical/Robot part/couvdroit.STL
mam_eurobot_2026/Mechanical/Robot part/garf2.STL
mam_eurobot_2026/Mechanical/Robot part/pinion.STL
mam_eurobot_2026/Mechanical/Robot part/pinion2.STL
mam_eurobot_2026/Mechanical/Robot part/pinionopp.STL
mam_eurobot_2026/Mechanical/Robot part/suppgauc.STL

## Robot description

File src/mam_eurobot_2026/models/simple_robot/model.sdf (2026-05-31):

<?xml version="1.0" ?>
<sdf version="1.9">
  <model name="simple_robot" canonical_link="base_link">
    <static>false</static>
    <pose>0 0 0 0 0 0</pose>

    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
    <link name="base_link">
      <pose relative_to="__model__">0 0 0.025 0 0 0</pose>
      <inertial>
        <mass>3.0</mass>
        <inertia>
          <ixx>0.0186</ixx>
          <ixy>0</ixy>
          <ixz>0</ixz>
          <iyy>0.0228</iyy>
          <iyz>0</iyz>
          <izz>0.0391</izz>
        </inertia>
      </inertial>
      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
    </link>

    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
    <link name="base_footprint">
      <pose relative_to="base_link">0 0 -0.025 0 0 0</pose>
    </link>
    
    <joint name="base_to_footprint" type="fixed">
      <parent>base_link</parent>
      <child>base_footprint</child>
    </joint>

    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
    <link name="left_wheel">
      <pose relative_to="base_link">-0.06 0.14 0 -1.5707 0 0</pose>
      <inertial>
        <mass>0.3</mass>
        <inertia>
          <ixx>0.000240</ixx>
          <ixy>0</ixy>
          <ixz>0</ixz>
          <iyy>0.000240</iyy>
          <iyz>0</iyz>
          <izz>0.000480</izz>
        </inertia>
      </inertial>
      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
    </link>

    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
    <link name="right_wheel">
      <pose relative_to="base_link">-0.06 -0.14 0 -1.5707 0 0</pose>
      <inertial>
        <mass>0.3</mass>
        <inertia>
          <ixx>0.000240</ixx>
          <ixy>0</ixy>
          <ixz>0</ixz>
          <iyy>0.000240</iyy>
          <iyz>0</iyz>
          <izz>0.000480</izz>
        </inertia>
      </inertial>
      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
    </link>

    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
    <link name="caster">
      <pose relative_to="base_link">0.11 0 -0.020 0 0 0</pose>
      <inertial>
        <mass>0.05</mass>
        <inertia>
          <ixx>0.00008</ixx>
          <ixy>0</ixy>
          <ixz>0</ixz>
          <iyy>0.00008</iyy>
          <iyz>0</iyz>
          <izz>0.00008</izz>
        </inertia>
      </inertial>
      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
    </link>

    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
    <link name="gripper_base">
      <pose relative_to="base_link">0.17 0 -0.02 0 0 0</pose>   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
      <inertial>
        <mass>0.3</mass>
        <inertia>
          <ixx>0.0002</ixx>
          <iyy>0.0002</iyy>
          <izz>0.0002</izz>
          <ixy>0</ixy>
          <ixz>0</ixz>
          <iyz>0</iyz>
        </inertia>
      </inertial>
      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
    </link>

    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
    <link name="left_finger">
      <pose relative_to="gripper_base">0.04  0.055 0.0 0 0 0</pose> 
      <inertial>
        <mass>0.08</mass>
        <inertia>
          <ixx>0.00008</ixx>
          <iyy>0.00002</iyy>
          <izz>0.00008</izz>
          <ixy>0</ixy>
          <ixz>0</ixz>
          <iyz>0</iyz>
        </inertia>
      </inertial>
      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
      <sensor name="left_finger_contact" type="contact">
    <always_on>true</always_on>
    <update_rate>200</update_rate>
    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
    <topic>/gripper/left/contact</topic>
  </sensor>
    </link>

    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
    <link name="right_finger">
      <pose relative_to="gripper_base">0.04  -0.055 0.0 0 0 0</pose>  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
      <inertial>
        <mass>0.08</mass>
        <inertia>
          <ixx>0.00008</ixx>
          <iyy>0.00002</iyy>
          <izz>0.00008</izz>
          <ixy>0</ixy>
          <ixz>0</ixz>
          <iyz>0</iyz>
        </inertia>
      </inertial>
      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
      <sensor name="right_finger_contact" type="contact">
  <always_on>true</always_on>
  <update_rate>200</update_rate>
  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
  <topic>/gripper/right/contact</topic>
</sensor>
    </link>

   
    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
    <link name="lidar_link">
      <pose relative_to="base_link">0 0 0.050 0 0 0</pose>
      <inertial>
        <mass>0.1</mass>
        <inertia>
          <ixx>0.00002</ixx>
          <iyy>0.00002</iyy>
          <izz>0.00002</izz>
          <ixy>0</ixy>
          <ixz>0</ixz>
          <iyz>0</iyz>
        </inertia>
      </inertial>
      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
      <sensor name="lidar_sensor" type="gpu_lidar">
        <topic>/scan</topic>
        <update_rate>10</update_rate>
        <always_on>true</always_on>
        <visualize>true</visualize>
        <lidar>
          <scan>
            <horizontal>
              <samples>360</samples>
              <resolution>1</resolution>
              <min_angle>-3.14159</min_angle>
              <max_angle>3.14159</max_angle>
            </horizontal>
            <vertical>
              <samples>1</samples>
              <resolution>1</resolution>
              <min_angle>0</min_angle>
              <max_angle>0</max_angle>
            </vertical>
          </scan>
          <range>
            <min>0.08</min>
            <max>10.0</max>
            <resolution>0.01</resolution>
          </range>
          <noise>
            <type>gaussian</type>
            <mean>0.0</mean>
            <stddev>0.01</stddev>
          </noise>
        </lidar>
        <frame_id>lidar_link</frame_id>
      </sensor>
    </link>

    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
    <link name="camera_link">
      <pose relative_to="base_link">0.10 0 0.20 0 0.7 0</pose>
      <inertial>
        <mass>0.05</mass>
        <inertia>
          <ixx>0.00001</ixx>
          <iyy>0.00001</iyy>
          <izz>0.00001</izz>
          <ixy>0</ixy>
          <ixz>0</ixz>
          <iyz>0</iyz>
        </inertia>
      </inertial>
      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
      <sensor name="camera_sensor" type="camera">
        <always_on>true</always_on>
        <update_rate>30</update_rate>
        <visualize>true</visualize>
        <camera>
          <horizontal_fov>1.047</horizontal_fov>
          <image>
            <width>640</width>
            <height>480</height>
            <format>R8G8B8</format>
          </image>
          <clip>
            <near>0.1</near>
            <far>100</far>
          </clip>
          <noise>
            <type>gaussian</type>
            <mean>0.0</mean>
            <stddev>0.007</stddev>
          </noise>
        </camera>
        <topic>/camera</topic>
      </sensor>
    </link>

    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
    <joint name="left_wheel_joint" type="revolute">
      <parent>base_link</parent>
      <child>left_wheel</child>
      <axis>
        <xyz>0 0 1</xyz>
        <limit>
          <lower>-1e16</lower>
          <upper>1e16</upper>
        </limit>
      </axis>
    </joint>

    <joint name="right_wheel_joint" type="revolute">
      <parent>base_link</parent>
      <child>right_wheel</child>
      <axis>
        <xyz>0 0 1</xyz>
        <limit>
          <lower>-1e16</lower>
          <upper>1e16</upper>
        </limit>
      </axis>
    </joint>

    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
    <joint name="caster_joint" type="fixed">
      <parent>base_link</parent>
      <child>caster</child>
    </joint>

    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
    <joint name="gripper_base_joint" type="fixed">
      <parent>base_link</parent>
      <child>gripper_base</child>
    </joint>

    <joint name="left_finger_joint" type="prismatic">
  <parent>gripper_base</parent>
  <child>left_finger</child>

  <axis>
    <xyz>0 1 0</xyz>

    <limit>
      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
      <lower>-0.04</lower>
      <upper>0.04</upper>
      <effort>40</effort>
      <velocity>0.05</velocity>
    </limit>

    <dynamics>
      <damping>3.0</damping>
      <friction>0.5</friction>
    </dynamics>
  </axis>
  </joint>


    <joint name="right_finger_joint" type="prismatic">
  <parent>gripper_base</parent>
  <child>right_finger</child>

  <axis>
    <xyz>0 -1 0</xyz>

    <limit>
      
      <lower>-0.04</lower>
      <upper>0.04</upper>
      <effort>40</effort>
      <velocity>0.05</velocity>
    </limit>

    <dynamics>
      <damping>3.0</damping>
      <friction>0.5</friction>
    </dynamics>
  </axis>
  </joint>



    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
    <joint name="lidar_joint" type="fixed">
      <parent>base_link</parent>
      <child>lidar_link</child>
    </joint>

    <joint name="camera_joint" type="fixed">
      <parent>base_link</parent>
      <child>camera_link</child>
    </joint>
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

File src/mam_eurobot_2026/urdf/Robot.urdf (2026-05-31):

<?xml version="1.0" encoding="utf-8"?>
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
<robot name="mam_eurobot_2026">
  <link name="base_link">
    <inertial>
      <origin xyz="-0.0023872 0 0.0033906" rpy="0 0 0" />
      <mass value="0.1672" />
      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
    </inertial>
    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
  </link>
  <link name="Left_Wheel">
    <inertial>
      <origin xyz="0.0175 0.058444 0.0085" rpy="0 0 0" />
      <mass value="0.063466" />
      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
    </inertial>
    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
  </link>
  <joint name="Joint_LW" type="continuous">
    <origin xyz="0 0 0" rpy="0 0 0" />
    <parent link="base_link" />
    <child link="Left_Wheel" />
    <axis xyz="0 1 0" />
  </joint>
  <link name="Right_Wheel">
    <inertial>
      <origin xyz="0.0175 -0.058444 0.0085" rpy="0 0 0" />
      <mass value="0.063466" />
      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
    </inertial>
    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
  </link>
  <joint name="Joint_RW" type="continuous">
    <origin xyz="0 0 0" rpy="0 0 0" />
    <parent link="base_link" />
    <child link="Right_Wheel" />
    <axis xyz="0 1 0" />
  </joint>
  <link name="Caster_Wheel">
    <inertial>
      <origin xyz="-0.066545 0.00089881 -0.005099" rpy="0 0 0" />
      <mass value="1.8842E-05" />
      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
    </inertial>
    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
  </link>
  <joint name="Joint_CW" type="continuous">
    <origin xyz="0 0 0" rpy="0 0 0" />
    <parent link="base_link" />
    <child link="Caster_Wheel" />
    <axis xyz="0 0 -1" />
  </joint>
  <link name="Gripper">
    <inertial>
      <origin xyz="-0.117150939235393 0.000470931920121931 -0.00299999996362621" rpy="0 0 0" />
      <mass value="0.00864824516024566" />
      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
    </inertial>
    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
  </link>
  <joint name="Joint_Gripper" type="fixed">
    <origin xyz="0 0 0" rpy="0 0 0" />
    <parent link="base_link" />
    <child link="Gripper" />
    <axis xyz="0 0 0" />
  </joint>
  <link name="Gripper_LL">
    <inertial>
      <origin xyz="-0.12346 0.040891 -0.0075" rpy="0 0 0" />
      <mass value="0.0032583" />
      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
    </inertial>
    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
  </link>
  <joint name="Joint_LL" type="revolute">
    <origin xyz="0 0 0" rpy="0 0 0" />
    <parent link="Gripper" />
    <child link="Gripper_LL" />
    <axis xyz="0 0 1" />
    <limit lower="0" upper="0" effort="0" velocity="0" />
  </joint>
  <link name="Left_Finger">
    <inertial>
      <origin xyz="-0.14886 0.093113 -0.003" rpy="0 0 0" />
      <mass value="0.0030344" />
      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
    </inertial>
    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
  </link>
  <joint name="Joint_LF" type="prismatic">
    <origin xyz="0 0 0" rpy="0 0 0" />
    <parent link="Gripper_LL" />
    <child link="Left_Finger" />
    <axis xyz="0 1 0" />
    <limit lower="0" upper="0" effort="0" velocity="0" />
  </joint>
  <link name="Gripper_RL">
    <inertial>
      <origin xyz="-0.12264 -0.039624 -0.0075" rpy="0 0 0" />
      <mass value="0.0034307" />
      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
    </inertial>
    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
  </link>
  <joint name="Joint_RL" type="revolute">
    <origin xyz="0 0 0" rpy="0 0 0" />
    <parent link="Gripper" />
    <child link="Gripper_RL" />
    <axis xyz="0 0 1" />
    <limit lower="0" upper="0" effort="0" velocity="0" />
  </joint>
  <link name="Right_Finger">
    <inertial>
      <origin xyz="-0.14735 -0.093226 -0.003" rpy="0 0 0" />
      <mass value="0.0030344" />
      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
    </inertial>
    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
  </link>
  <joint name="Joint_RF" type="prismatic">
    <origin xyz="0 0 0" rpy="0 0 0" />
    <parent link="Gripper_RL" />
    <child link="Right_Finger" />
    <axis xyz="0 1 0" />
    <limit lower="0" upper="0" effort="0" velocity="0" />
  </joint>
  <link name="Surround">
    <inertial>
      <origin xyz="0.0015244 5.5511E-16 0.056392" rpy="0 0 0" />
      <mass value="0.16147" />
      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
    </inertial>
    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
  </link>
  <joint name="Joint_Surround" type="fixed">
    <origin xyz="0 0 0" rpy="0 0 0" />
    <parent link="base_link" />
    <child link="Surround" />
    <axis xyz="0 0 0" />
  </joint>
  <link name="Top_Chasis">
    <inertial>
      <origin xyz="0.0032523 0 0.10913" rpy="0 0 0" />
      <mass value="0.18716" />
      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
    </inertial>
    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
  </link>
  <joint name="Joint_TB" type="fixed">
    <origin xyz="0 0 0" rpy="0 0 0" />
    <parent link="base_link" />
    <child link="Top_Chasis" />
    <axis xyz="0 0 0" />
  </joint>
</robot>

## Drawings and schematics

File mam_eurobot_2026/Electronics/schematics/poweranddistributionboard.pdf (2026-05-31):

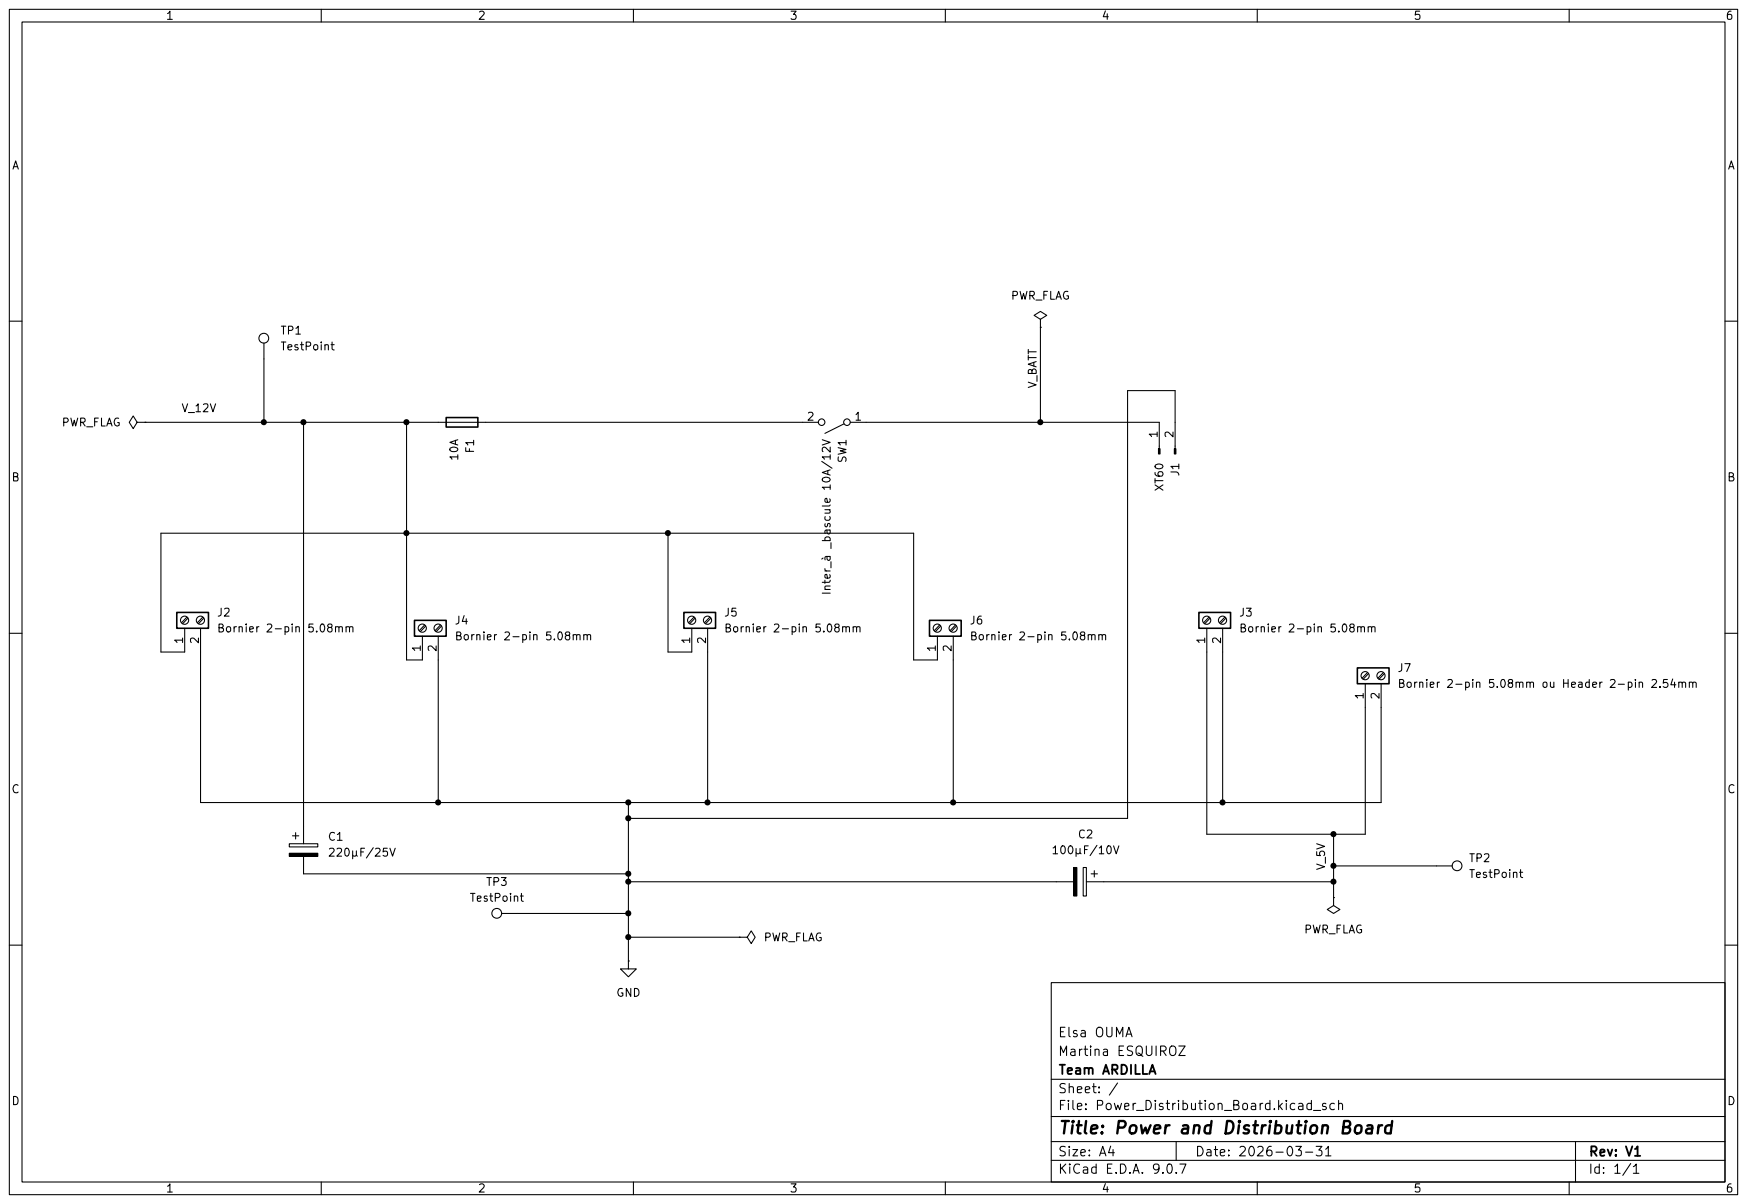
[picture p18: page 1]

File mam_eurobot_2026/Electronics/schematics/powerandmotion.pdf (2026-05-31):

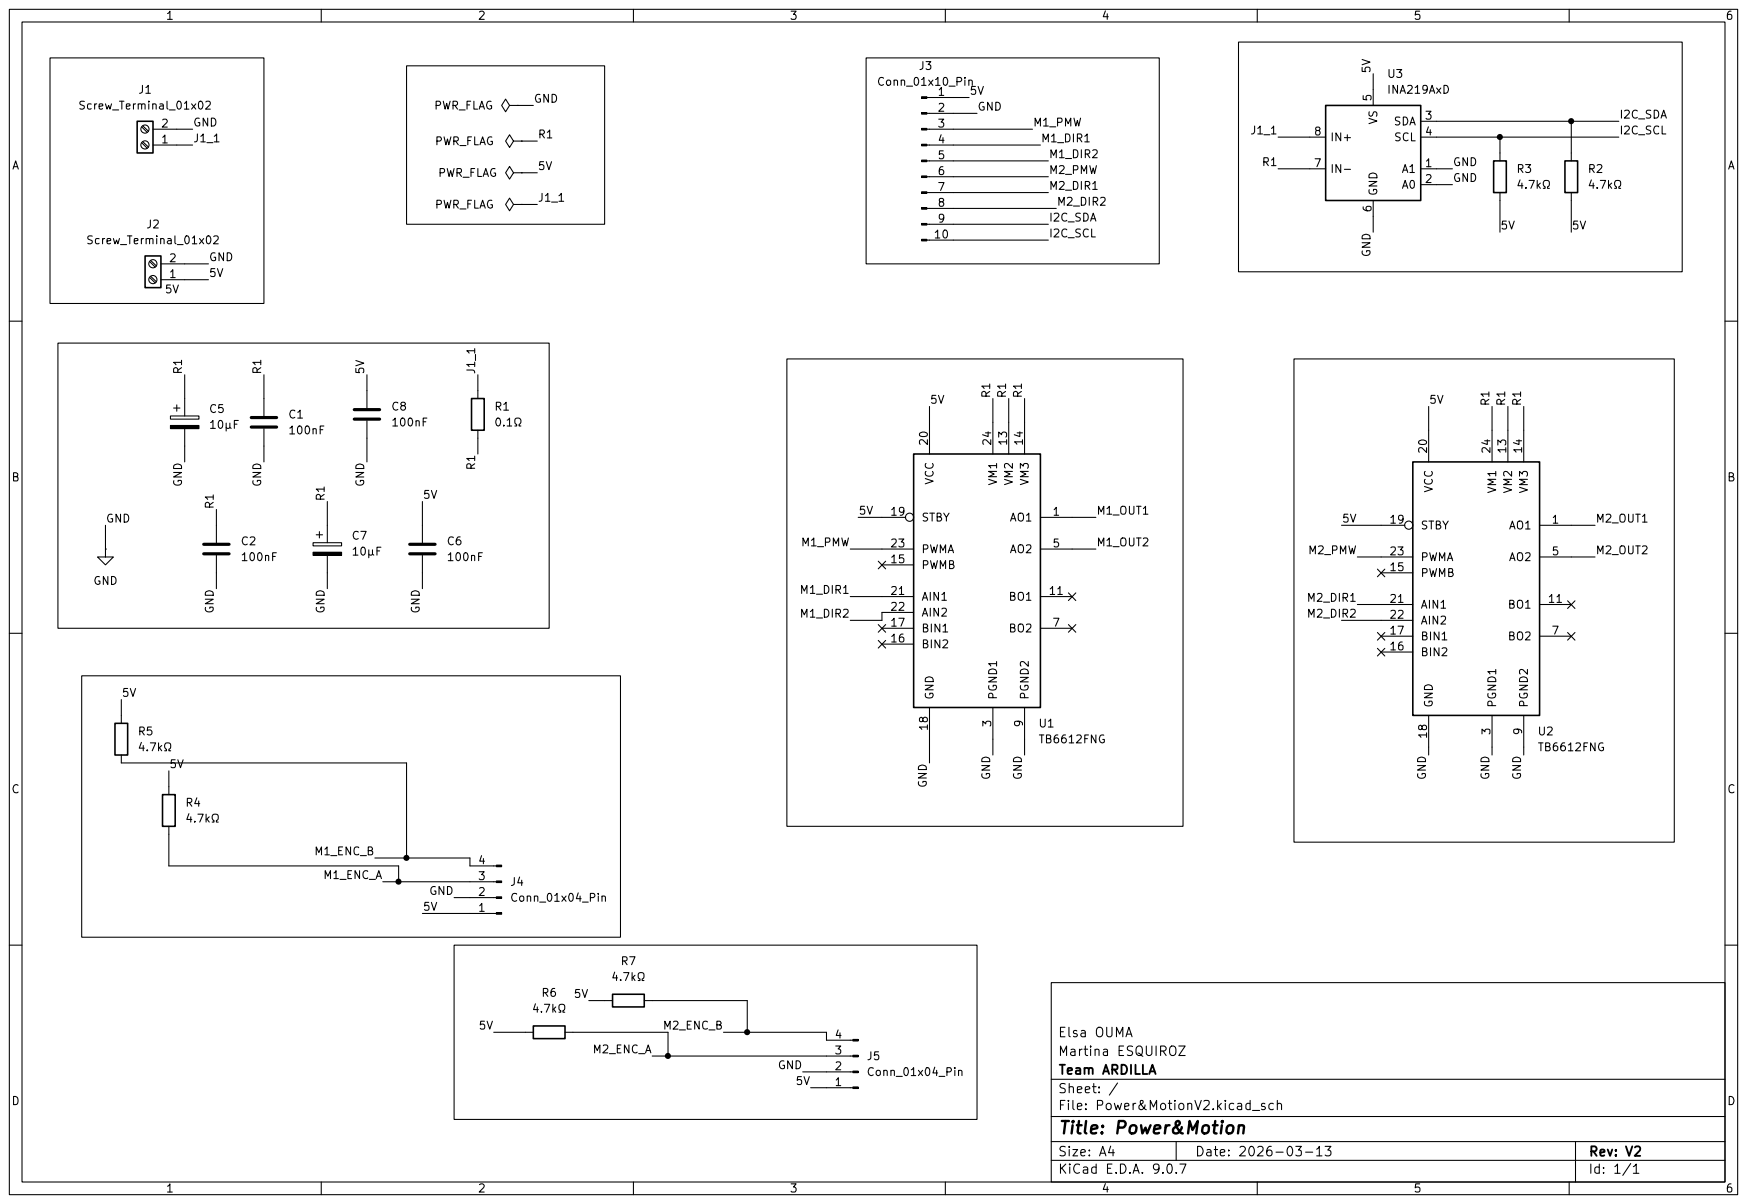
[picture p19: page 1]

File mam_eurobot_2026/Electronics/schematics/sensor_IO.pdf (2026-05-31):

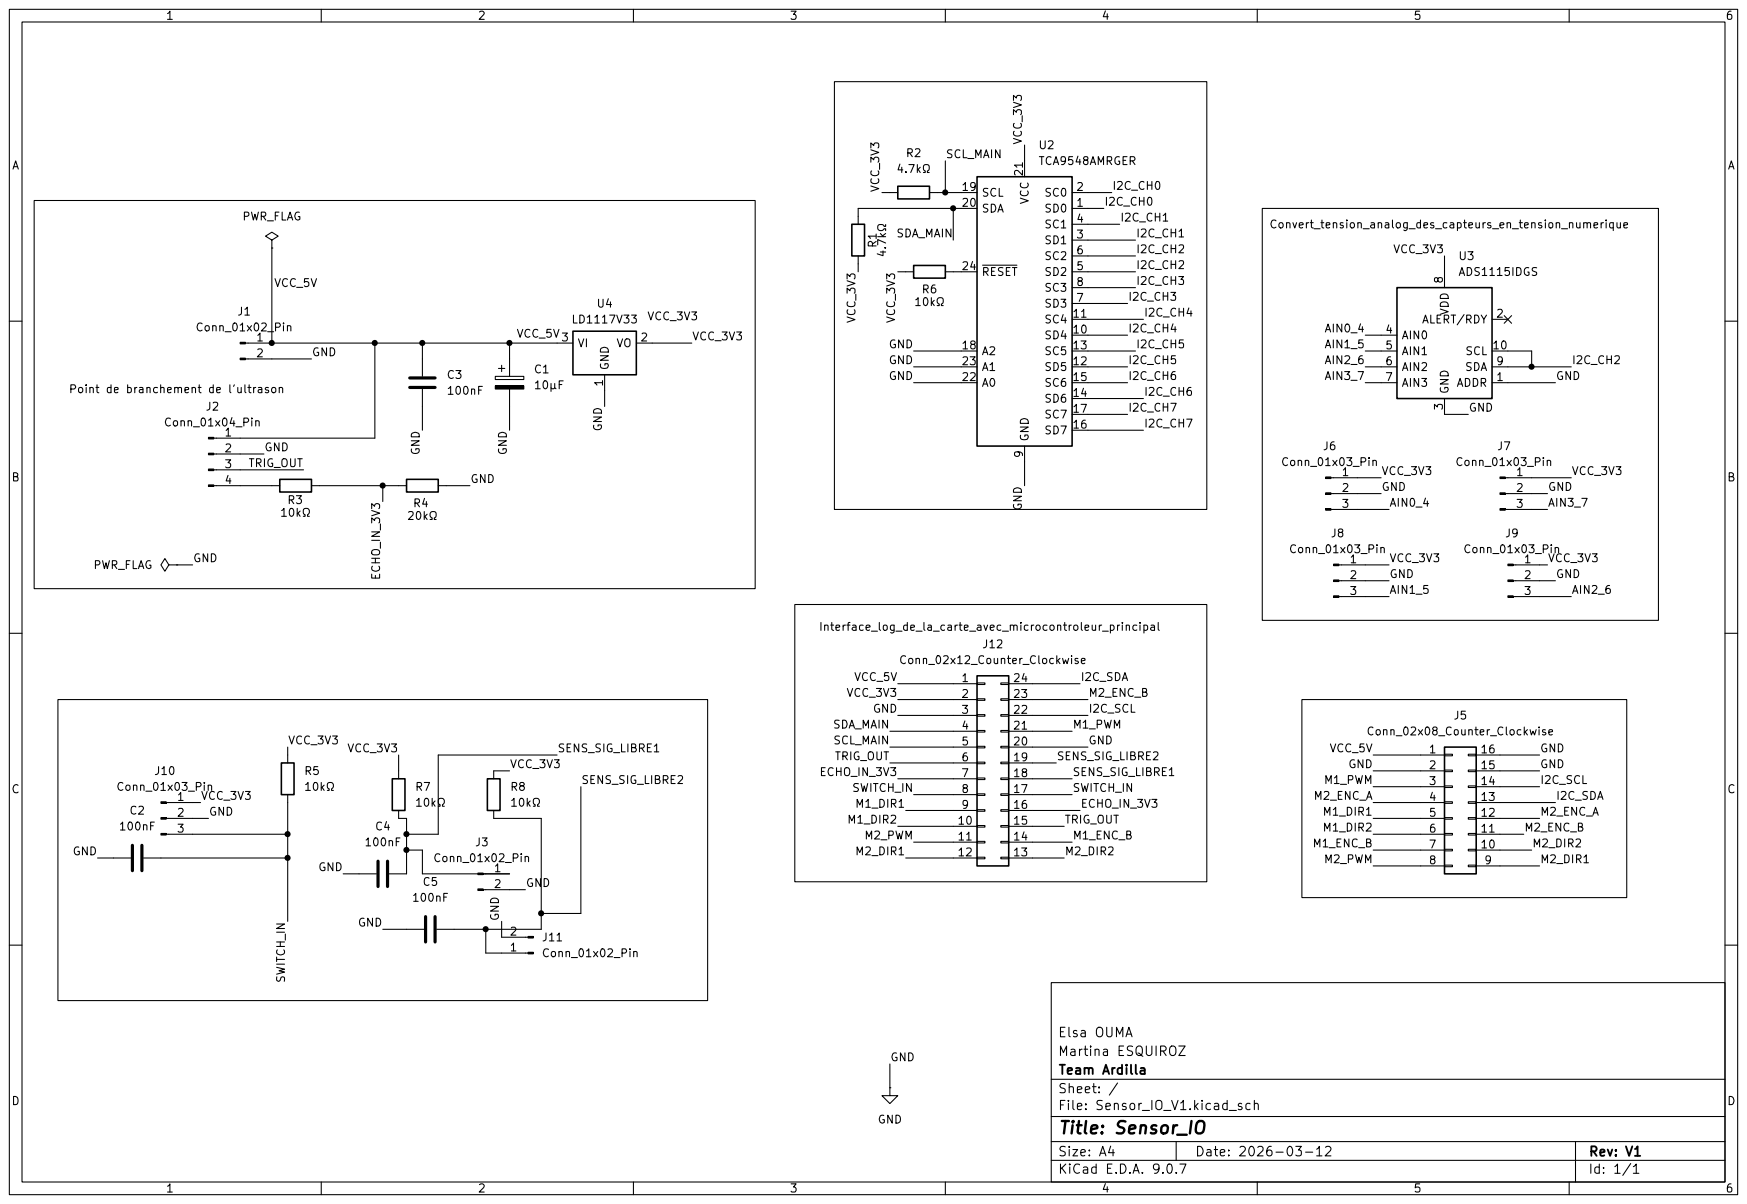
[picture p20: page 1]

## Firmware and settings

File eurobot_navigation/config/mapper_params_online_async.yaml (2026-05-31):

slam_toolbox:
  ros__parameters:

    # Plugin params
    solver_plugin: solver_plugins::CeresSolver
    ceres_linear_solver: SPARSE_NORMAL_CHOLESKY
    ceres_preconditioner: SCHUR_JACOBI
    ceres_trust_strategy: LEVENBERG_MARQUARDT
    ceres_dogleg_type: TRADITIONAL_DOGLEG
    ceres_loss_function: None

    # ROS Parameters
    odom_frame: odom
    map_frame: map
    base_frame: base_link
    scan_topic: /scan_fixed
    use_map_saver: true
    mode: mapping #mapping | localization

    # if you'd like to immediately start continuing a map at a given pose
    # or at the dock, but they are mutually exclusive, if pose is given
    # will use pose
    # map_file_name: /root/eurobot_ws/eurobot_map.yaml  #test_steve
    # map_start_pose: [0.0, 0.0, 0.0]
    #map_start_at_dock: true

    debug_logging: false
    throttle_scans: 1
    transform_publish_period: 0.02 #if 0 never publishes odometry
    map_update_interval: 5.0
    resolution: 0.05
    restamp_tf: false
    min_laser_range: 0.0 #for rastering images
    max_laser_range: 20.0 #for rastering images
    minimum_time_interval: 0.5
    transform_timeout: 0.2
    tf_buffer_duration: 30.0
    stack_size_to_use: 40000000 #// program needs a larger stack size to serialize large maps
    enable_interactive_mode: true

    # General Parameters
    use_scan_matching: true
    use_scan_barycenter: true
    minimum_travel_distance: 0.5
    minimum_travel_heading: 0.5
    scan_buffer_size: 10
    scan_buffer_maximum_scan_distance: 10.0
    link_match_minimum_response_fine: 0.1  
    link_scan_maximum_distance: 1.5
    loop_search_maximum_distance: 3.0
    do_loop_closing: true 
    loop_match_minimum_chain_size: 10           
    loop_match_maximum_variance_coarse: 3.0  
    loop_match_minimum_response_coarse: 0.35    
    loop_match_minimum_response_fine: 0.45

    # Correlation Parameters - Correlation Parameters
    correlation_search_space_dimension: 0.5
    correlation_search_space_resolution: 0.01
    correlation_search_space_smear_deviation: 0.1 

    # Correlation Parameters - Loop Closure Parameters
    loop_search_space_dimension: 8.0
    loop_search_space_resolution: 0.05
    loop_search_space_smear_deviation: 0.03

    # Scan Matcher Parameters
    distance_variance_penalty: 0.5      
    angle_variance_penalty: 1.0    

    fine_search_angle_offset: 0.00349     
    coarse_search_angle_offset: 0.349   
    coarse_angle_resolution: 0.0349        
    minimum_angle_penalty: 0.9
    minimum_distance_penalty: 0.5
    use_response_expansion: true
    min_pass_through: 2
    occupancy_threshold: 0.1
